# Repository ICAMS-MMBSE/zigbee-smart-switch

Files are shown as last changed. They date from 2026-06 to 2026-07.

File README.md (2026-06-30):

# zigbee-smart-switch

A Zigbee-based smart switch system for remote dehumidifier control, built for Industry 4.0 reliability, connectivity, and remote management.

## Purpose
- Build a smart switch to control a system of dehumidifiers remotely
- Integrate IoT connection through Mosquitto

### High-Level System Diagram

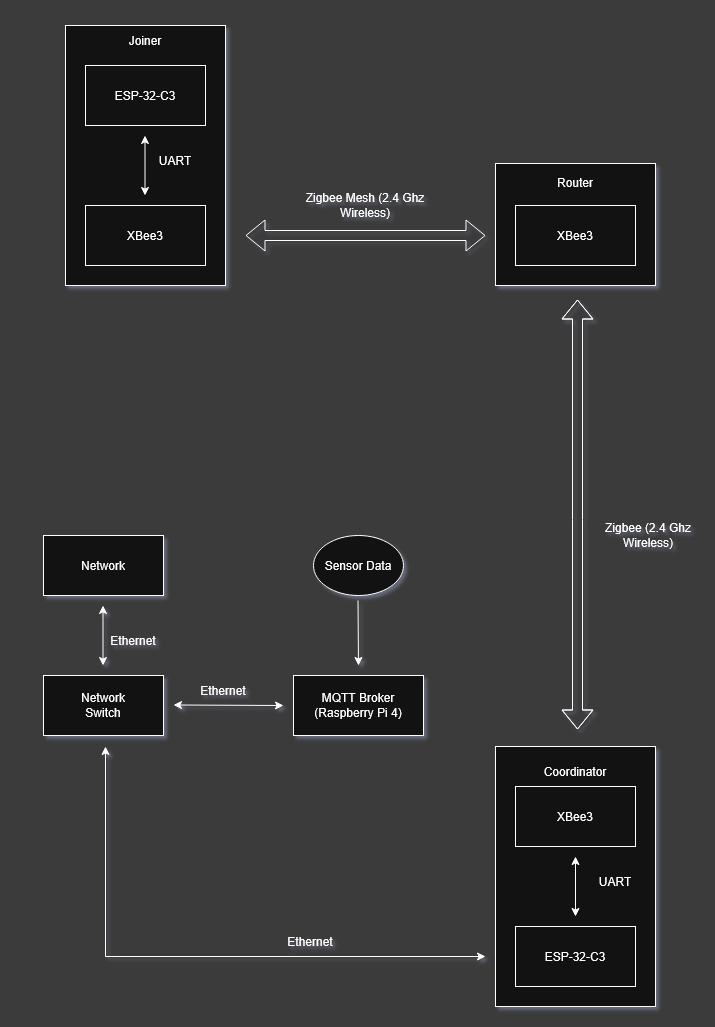
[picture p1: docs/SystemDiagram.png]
System Diagram


## Frameworks & Software

| Tool | Purpose |
|---|---|
| [Digi XCTU](https://www.digi.com/products/embedded-systems/digi-xbee/digi-xbee-tools/xctu) | Programs XBee modules |
| [PlatformIO](https://platformio.org/) | Build system and library manager for all firmware |
| [Mosquitto](https://github.com/eclipse-mosquitto/mosquitto) | MQTT broker |

## Firmware

Firmware is written in C using the ESP-IDF framework with FreeRTOS, built and flashed via VS Code with the PlatformIO extension.

### Setup

1. Install [VS Code](https://code.visualstudio.com/) and the [PlatformIO extension](https://platformio.org/install/ide?install=vscode)
2. Open `coord_esp32-c3/` or `join_esp32-c3/` as the workspace root in VS Code
3. PlatformIO will auto-detect the target from `platformio.ini`
4. Build and flash via the PlatformIO toolbar, or `pio run -t upload`

### Programming the XBee Modules

> **Note:** You **must** use the XBee Grove Development Board and XCTU to program the XBee modules. Plug in with USB micro-B and add device to XCTU.

| | Coordinator | Joiner | Router |
| --- | --- | --- | --- |
| **CE** Device Role | Form Network [1] | Join Network [0] | Join Network [0] |
| **ID** Extended PAN ID | 1234 | 1234 | 1234 |
| **JV** Coordinator Verification | Enabled [1] | Disabled [0] | Disabled [0] |
| **JN** Join Notification | Disabled [0] | Enabled [1] | Enabled [1] |
| **NI** Node Identifier | SS_Comm | SS_x (0...) | RT_x (0...) |
| **BD** UART Baud Rate | 115200 | 115200 | 115200 |
| **AP** API Enable | API Mode Without Escapes [1] | API Mode Without Escapes [1] | API Mode Without Escapes [1] |
| **SM** Sleep Mode | No Sleep [0] | No Sleep [0] | No Sleep [0] |
| **EE** Encryption Enable | Disabled [0] | Disabled [0] | Disabled [0] |

### Firmware Structure

#### Coordinator (`firmware/coord_esp32-c3/`)
```
config.h
xbee.h/.c       — raw API frame TX/RX, AT commands, ping, RX task
discovery.h/.c  — ND-based dynamic node table
relay.h/.c      — command routing
button.h/.c     — physical button, triggers toggle to all nodes
ethernet.h/.c   — W5500 SPI ethernet, DHCP
mqtt.h/.c       — MQTT client, command handler (switch/+/cmd), state publisher
main.c
```

#### Joiner (`firmware/joiner_esp32-c3/`)
```
config.h
xbee.h/.c       — raw API frame TX/RX, state reporting
relay.h/.c      — relay GPIO control
button.h/.c     — manual override, reports state to coordinator
main.c
```

### Key Technical Notes

- All XBee communication uses manually constructed raw API frames
- Frame types used: `0x10` ZBTxRequest, `0x08` AT command, `0x88` AT response, `0x90` ZB RX, `0x8B` TX status

## Hardware

### Coordinator
- ESP32-C3 Super Mini + XBee3 Zigbee 3.0 TH + W5500 Ethernet

### Joiner
- ESP32-C3 Super Mini + XBee3 Zigbee 3.0 TH

## Raspberry Pi Broker Setup

The Pi runs a Mosquitto MQTT broker and connects directly to the coordinator via ethernet.

### Mosquitto
```bash
sudo apt update && sudo apt install -y mosquitto mosquitto-clients
sudo systemctl enable mosquitto
printf 'listener 1883\nallow_anonymous true\n' | sudo tee /etc/mosquitto/conf.d/local.conf
sudo systemctl restart mosquitto
```

### Broker Connection

The coordinator connects to the broker at a hardcoded hostname in `mqtt.c`:

```c
.broker.address.uri = "mqtt://rpi3.local:1883"
```

> **Production note:** This hostname is compiled into the firmware. If the broker host changes (different Pi, renamed host, or production deployment), update the URI in `mqtt.c` and reflash the coordinator. A `.local` hostname requires mDNS resolution to be enabled in the firmware (`CONFIG_LWIP_DNS_SUPPORT_MDNS_QUERIES=y`); if mDNS resolution is unreliable on the network, substitute the broker's IP address directly. A future revision could replace this with mDNS service discovery (`_mqtt._tcp`) to remove the hardcoded dependency entirely.

### MQTT Topics
| Topic | Direction | Description |
|---|---|---|
| `switch/all/cmd` | Pi → Coordinator | Command all nodes |
| `switch/SS_<n>/cmd` | Pi → Coordinator | Command individual node |
| `switch/SS_<n>/state` | Coordinator → Pi | Per-node joiner state report |

Supported commands: `ON`, `OFF`, `TOGGLE`, `POLL`

### Examples
```bash
# All nodes on / off
mosquitto_pub -h localhost -t "switch/all/cmd" -m "ON"
mosquitto_pub -h localhost -t "switch/all/cmd" -m "OFF"

# Individual node
mosquitto_pub -h localhost -t "switch/SS_0/cmd" -m "ON"
mosquitto_pub -h localhost -t "switch/SS_1/cmd" -m "TOGGLE"

# Poll without changing state
mosquitto_pub -h localhost -t "switch/SS_1/cmd" -m "POLL"
mosquitto_pub -h localhost -t "switch/SS_0/cmd" -m "POLL"

# Subscribe to all state updates
mosquitto_sub -h localhost -t "switch/+/state" -v
```

## References
- [Digi XBee 3](https://hub.digi.com/support/products/digi-xbee/digi-xbee3/)
- [Digi XBee API Frame Reference](https://docs.digi.com/resources/documentation/digidocs/rf-docs/blu/blu-api-frames_c.html)
- [XBee Grove Development Board User Guide](https://docs.digi.com/resources/documentation/digidocs/pdfs/90001457-13.pdf)
- [ESP-IDF Programming Guide](https://docs.espressif.com/projects/esp-idf/en/latest/)
- [Digi XBee Python Library (not used, but helpful)](https://xbplib.readthedocs.io/en/latest/index.html)

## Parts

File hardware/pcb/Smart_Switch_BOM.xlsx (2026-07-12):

Coordinator & Joiner BOM: | Note: | This list includes parts for 1 Coordinator, 3 Joiners, and 3 Routers (initial demo order) |  |  |  | PCB Manufacturers: | Note: The minimum number of boards is 5
Part | Qty. | Price | Purpose | Board | Already Have? |  | PCB Way | JLPCB
ESP32-C3 Super Mini (10 PCS) (https://www.amazon.com/ESP32-C3-Development-Bluetooth-Running-Frequency/dp/B0DFWG87JS) | 10 | $29.69 | Logic MCU | Coordinator & Joiner | X | Coordinator Boards x5 | $5.00 | $4.00
XB3-24Z8UT-J (https://www.digikey.com/en/products/detail/digi/XB3-24Z8UT-J/8130933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) | 7 | $23.52 (each) | Radio Module | All | 5 | Joiner Boards x5 | $27.00 | $8.70
WIZ850IO (https://www.digikey.com/en/products/detail/wiznet/WIZ850IO/8789619) | 1 | $20.36 | Coord. Ethernet | Coordinator | X | Router Boards x5 | $5.00 | $4.00
Adafruit USB-C breakout 4090 (https://www.digikey.com/en/products/detail/adafruit-industries-llc/4090/9951930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) | 4 | $2.95 | Coord. & Routers USB-C Power | Coordinator & Router | X | Build Time | 3-4 days | 3 days
10kΩ resistor | 7 | X | Xbee RST pull-up | All | ✓ | Offers / Coupons | $5.00 off | $15.00 off
5.1kΩ resistor | 4 | X | USB-C CC | Coordinator & Router | ✓ | Shipping (all ordered together) | $30.30 | $28.12
330Ω resistor | 3 | X | Relay Transistor Base connection | Joiner | ✓ | Total cost (all ordered together, with coupon) | $84.42 | $27.82
5mm LED | 3 | X | Joiner Debug LED | Joiner | ✓
Push Button (https://www.digikey.com/en/products/detail/e-switch/RP3502ARED/280448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) | 3 | $2.32 (each) | Manual switch | Joiner | X
2N3904 NPN transistor | 3 | X | Relay switching logic | Joiner | ✓
1x08 Female 2.54mm Header | 12 | X | ESP-32 and USB-C Headers | All | ✓
1x10 Female 2.00mm Header (https://www.digikey.com/en/products/detail/sullins-connector-solutions/NPPN101BFCN-RC/804812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) | 14 | $0.72 (each) | XBee3 Headers | All | X
1x06 Female 2.54mm Header | 2 | X | Ethernet Module Headers | Coordinator | ✓
HLK-PM12 (3 PCS) (https://www.amazon.com/dp/B0B63WP3LF?lv=shuf&channelId=500&plpRedirect=mhFallback&th=1) | 3 | $13.99 | 120V to 12V converter | Joiner | X
HLK-PM01 (5 PCS) (https://www.amazon.com/dp/B01B7G6LYE?lv=shuf&channelId=500&plpRedirect=mhFallback&th=1) | 5 | $18.51 | 120V to 5V converter | Joiner | X
30A Relay (https://www.digikey.com/en/products/detail/te-connectivity-potter-brumfield-relays/T9AS1D12-12/254519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) | 3 | $6.35 (each) | 30A Relay Switching Mains In | Joiner | X
1N4007 Diode | 3 | X | Flyback Diode | Joiner | ✓
100Ω 1W resistor (https://www.digikey.com/en/products/detail/yageo/MFR100FTF52-100R/9131275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) | 3 | $0.21 (each) | Snubber | Joiner | X
0.1µF X2 275VAC cap (https://www.digikey.com/en/products/detail/tdk/B32922C3104K026/21191938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) | 3 | $0.54 (each) | Snubber | Joiner | X
Fuse Holder, 6.3 x 32mm, 300V, 15A (https://www.digikey.com/en/products/detail/eaton-electronics-division/BK-S-8002-1X-R/1877082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) | 3 | $1.12 (each) | Fuse holder | Joiner | X
Fuse, 6.3 x 32mm, Glass, Slow-Blow, 250V, 15A (https://www.digikey.com/en/products/detail/eaton-electronics-division/BK-MDL-15-R/954320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) | 3 | $1.95 (each) | Fuse to protect line in | Joiner | X
Screw Terminals (https://www.digikey.com/en/products/detail/phoenix-contact/1729131/260616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) | 6 | $1.44 (each) | Connects mains in and mains out | Joiner | X
Male IEC Connector (https://www.digikey.com/en/products/detail/adam-tech/IEC-A-2/9832396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) | 3 | $1.45 (each) | Mains in connection | Joiner | X
Female NEMA Connector (https://www.digikey.com/en/products/detail/qualtek/739W-X2-03/245569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) | 3 | $1.47 (each) | Mains out (dehumid) connection | Joiner | X
12 AWG Wire 10' (https://www.digikey.com/en/products/detail/remington-industries/SJOOW1203-10/14318220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) | 2 | $58.95 | Mains connections | Joiner | X
U.FL to RP-SMA (https://www.digikey.com/en/products/detail/sparkfun-electronics/18569/15652895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) | 7 | $2.94 (each) | Connects antenna to XBee3 | All | X
2.4GHZ DIPOLE ANTENNA RP-SMA (https://www.digikey.com/en/products/detail/te-connectivity-linx/ANT-2.4-LCW-RPS/9607800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) | 7 | $3.76 (each) | Antenna for range | All | X
LDO (https://www.digikey.com/en/products/detail/texas-instruments/TLV75733PDBVR/9343364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) | 3 | $0.34 (each) | Convert 5V USB to 3.3V | Router | X

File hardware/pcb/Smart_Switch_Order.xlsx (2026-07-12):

Smart Switch Components & PCBs:
Part | Qty. | Price
ESP32-C3 Super Mini (10 PCS) (https://www.amazon.com/ESP32-C3-Development-Bluetooth-Running-Frequency/dp/B0DFWG87JS) | 10 | $29.69
WIZ850IO (https://www.digikey.com/en/products/detail/wiznet/WIZ850IO/8789619) | 1 | $20.36
Adafruit USB-C breakout 4090 (https://www.digikey.com/en/products/detail/adafruit-industries-llc/4090/9951930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) | 4 | 2.95 (each)
Push Button (https://www.digikey.com/en/products/detail/e-switch/RP3502ARED/280448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) | 3 | $2.32 (each)
1x10 Female 2.00mm Header (https://www.digikey.com/en/products/detail/sullins-connector-solutions/NPPN101BFCN-RC/804812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) | 14 | $0.72 (each)
HLK-PM12 (3 PCS) (https://www.amazon.com/dp/B0B63WP3LF?lv=shuf&channelId=500&plpRedirect=mhFallback&th=1) | 3 | $13.99
HLK-PM01 (5 PCS) (https://www.amazon.com/dp/B01B7G6LYE?lv=shuf&channelId=500&plpRedirect=mhFallback&th=1) | 5 | $18.51
30A Relay (https://www.digikey.com/en/products/detail/te-connectivity-potter-brumfield-relays/T9AS1D12-12/254519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) | 3 | $6.35 (each)
100Ω 1W resistor (https://www.digikey.com/en/products/detail/yageo/MFR100FTF52-100R/9131275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) | 3 | $0.21 (each)
0.1µF X2 275VAC cap (https://www.digikey.com/en/products/detail/tdk/B32922C3104K026/21191938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) | 3 | $0.54 (each)
Fuse Holder, 6.3 x 32mm, 300V, 15A (https://www.digikey.com/en/products/detail/eaton-electronics-division/BK-S-8002-1X-R/1877082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) | 3 | $1.12 (each)
Fuse, 6.3 x 32mm, Glass, Slow-Blow, 250V, 15A (https://www.digikey.com/en/products/detail/eaton-electronics-division/BK-MDL-15-R/954320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) | 3 | $1.95 (each)
Screw Terminals (https://www.digikey.com/en/products/detail/phoenix-contact/1729131/260616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) | 6 | $1.44 (each)
Male IEC Connector (https://www.digikey.com/en/products/detail/adam-tech/IEC-A-2/9832396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) | 3 | $1.45 (each)
Female NEMA Connector (https://www.digikey.com/en/products/detail/qualtek/739W-X2-03/245569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) | 3 | $1.47 (each)
12 AWG Wire 10' (https://www.digikey.com/en/products/detail/remington-industries/SJOOW1203-10/14318220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) | 1 | $58.95
U.FL to RP-SMA (https://www.digikey.com/en/products/detail/sparkfun-electronics/18569/15652895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) | 7 | $2.94 (each)
2.4GHZ DIPOLE ANTENNA RP-SMA (https://www.digikey.com/en/products/detail/te-connectivity-linx/ANT-2.4-LCW-RPS/9607800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) | 7 | $3.76 (each)
LDO (https://www.digikey.com/en/products/detail/texas-instruments/TLV75733PDBVR/9343364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) | 3 | $0.34 (each)
PCB Manufacturers: | Note: The minimum number of boards is 5
 | PCB Way | JLPCB
Coordinator Boards x5 | $5.00 | $4.00
Joiner Boards x5 | $27.00 | $8.70
Router Boards x5 | $5.00 | $4.00
Build Time | 3-4 days | 3 days
Offers / Coupons | $5.00 off | $15.00 off
Shipping (all ordered together) | $30.30 | $28.12
Total cost (all ordered together, with coupon) | $84.42 | $27.82
PCBWay (https://www.pcbway.com/?adwgc=666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)
JLCPCB (https://jlcpcb.com/?from=VGSU&gad_source=1&gad_campaignid=14179457750)

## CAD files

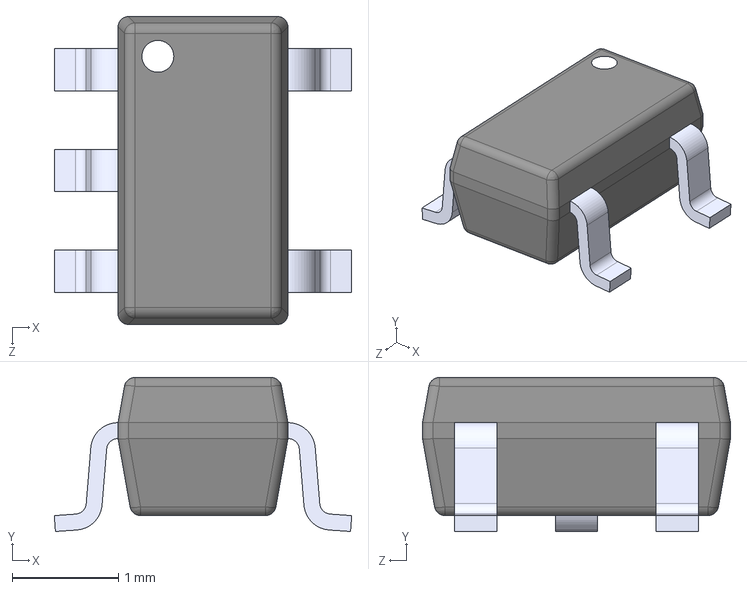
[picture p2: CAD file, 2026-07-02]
hardware/pcb/router/TLV75733PDBVR/TLV75733PDBVR.step
2.80 x 1.45 x 2.90 mm

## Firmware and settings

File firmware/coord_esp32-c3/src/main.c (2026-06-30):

#include "freertos/FreeRTOS.h"
#include "freertos/task.h"
#include "driver/uart.h"
#include "esp_log.h"
#include "ethernet.h"
#include "mqtt.h"
#include "xbee.h"
#include "discovery.h"
#include "relay.h"
#include "button.h"
#include "config.h"
#include <string.h>
#include <stdio.h>

static const char *TAG = "MAIN";

// Read newline-terminated commands from UART0 (USB serial) and dispatch them
static void console_task(void *arg)
{
    uart_config_t cfg = {
        .baud_rate  = 115200,
        .data_bits  = UART_DATA_8_BITS,
        .parity     = UART_PARITY_DISABLE,
        .stop_bits  = UART_STOP_BITS_1,
        .flow_ctrl  = UART_HW_FLOWCTRL_DISABLE,
    };
    uart_driver_install(UART_NUM_0, 256 * 2, 0, 0, NULL, 0);
    uart_param_config(UART_NUM_0, &cfg);

    uint8_t buf[128];
    uint8_t idx = 0;

    while (1) {
        uint8_t b;
        if (uart_read_bytes(UART_NUM_0, &b, 1, pdMS_TO_TICKS(10)) != 1) continue;

        if (b == '\n' || b == '\r') {
            if (idx == 0) continue;
            buf[idx] = '\0';
            char *cmd = (char *)buf;
            idx = 0;

            if (strcmp(cmd, "AT_PING") == 0) {
                xbee_ping();
            } else if (strcmp(cmd, "DISCOVER") == 0) {
                discover_nodes();
                print_node_table();
            } else if (strcmp(cmd, "NODES") == 0) {
                print_node_table();
            } else if (strncmp(cmd, "RELAY ", 6) == 0) {
                // Format: RELAY <nodeId> <0|1>
                char    node_id[16];
                uint8_t state;
                sscanf(cmd + 6, "%15s %hhu", node_id, &state);
                relay_cmd(node_id, state);
            } else if (strncmp(cmd, "TOGGLE ", 7) == 0) {
                relay_toggle(cmd + 7);
            } else if (strncmp(cmd, "POLL ", 5) == 0) {
                relay_poll(cmd + 5);
            } else {
                ESP_LOGW(TAG, "Unknown command: %s", cmd);
            }
        } else {
            if (idx < 127) buf[idx++] = b;
        }
    }
}

void app_main(void)
{
    ESP_LOGI(TAG, "Commissioner starting...");
    ethernet_init();
    button_init();
    xbee_init();
    vTaskDelay(pdMS_TO_TICKS(2000)); // let XBee3 boot
    discover_nodes();
    print_node_table();
    vTaskDelay(pdMS_TO_TICKS(3000)); // give joiners time to settle before polling
    relay_poll("ALL");
    xTaskCreate(xbee_task,    "xbee_task",    4096, NULL, 5, NULL);
    xTaskCreate(button_task,  "button_task",  2048, NULL, 5, NULL);
    xTaskCreate(console_task, "console_task", 4096, NULL, 4, NULL);
    mqtt_init();
    ESP_LOGI(TAG, "Commissioner ready");
}

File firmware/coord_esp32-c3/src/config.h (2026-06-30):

#pragma once
#include "driver/gpio.h"
#include "driver/uart.h"

// Pin definitions
#define BTN_PIN     GPIO_NUM_3
#define XBEE_RX     GPIO_NUM_1
#define XBEE_TX     GPIO_NUM_0
// UART
#define XBEE_UART       UART_NUM_1
#define XBEE_BAUD       115200
#define UART_BUF_SIZE   256
// XBee command bytes
#define CMD_OFF    0x00
#define CMD_ON     0x01
#define CMD_TOGGLE 0x02
#define CMD_POLL   0x03
// Node table
#define MAX_NODES 10
// W5500 SPI pins
#define W5500_SCLK  GPIO_NUM_5
#define W5500_MOSI  GPIO_NUM_7
#define W5500_MISO  GPIO_NUM_8
#define W5500_CS    GPIO_NUM_6
#define W5500_INT   GPIO_NUM_9
#define W5500_RST   GPIO_NUM_10

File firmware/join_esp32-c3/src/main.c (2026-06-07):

#include "freertos/FreeRTOS.h"
#include "freertos/task.h"
#include "esp_log.h"
#include "relay.h"
#include "button.h"
#include "xbee.h"

static const char *TAG = "MAIN";

void app_main(void)
{
    ESP_LOGI(TAG, "Joiner starting...");

    relay_init();
    button_init();
    xbee_init();

    xTaskCreate(xbee_task,   "xbee_task",   4096, NULL, 5, NULL);
    xTaskCreate(button_task, "button_task", 2048, NULL, 5, NULL);

    ESP_LOGI(TAG, "Joiner ready");
}

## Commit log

2026-05-17 Added joiner and commissioner communication sketches. Verified by onboard LED and pushbutton
2026-05-19 Wired FW to ZSS CLI swtich
2026-05-19 library import for kicad + readme update
    [XBee3_SMT.step, commissioner.kicad_pcb, commissioner.kicad_sch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]
2026-05-20 arduino outline addition
    [arduino_r4_outline.FCStd]
2026-05-21 arduino case, kicad basic setup
    [arduino_r4_case.FCStd, commissioner.kicad_sch, joiner.kicad_sch]
2026-05-25 Completed CommisionerV1 PCB design
    [XBee3_SMT.step, arduino_r4_case.FCStd, arduino_r4_outline.FCStd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]
2026-06-07 Migrate smart switch firmware from Arduino to ESP32 (S3/C3). Complete rewrite using ESP-IDF and FreeRTOS. Commissioner moves to ESP32-S3, joiner to ESP32-C3. Adds 2-way communication so the joiner re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
    [button.c, config.h, discovery.c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]
2026-06-07 W5500 ethernet and MQTT integration on commissioner
    - W5500 SPI ethernet via esp-eth-drivers component (SPI2, IO10-13)
    - Static IP 192.168.2.10 on commissioner, Pi broker at 192.168.2.1
    - esp-mqtt client subscribes to switch/all/cmd and switch/1/cmd
    - Publishes joiner state to switch/SS_1/state on change or poll
    - POLL command added to MQTT command handler
    - Joiner button press now reports state back to commissioner via XBee
    - Added W5500 pin definitions to config.h
    - Added Pi broker setup instructions to README
    [config.h, ethernet.c, main.c]
2026-06-16 Added eth, MQTT. Migrated coord from esp32-s3 to c3.
2026-06-22 Finished Coordinator PCB Design
    [ESP32-C3_SUPERMINI_TH.step, XBee3_SMT.step, commissioner_v1.kicad_pcb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]
2026-06-22 Joiner PCB began
    [Smart Switch BOM.xlsx, coordinator.kicad_pcb, coordinator.kicad_sch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]
2026-06-23 Made Joiner PCB Progress
    [ESP32-C3_SUPERMINI_TH.step, HLK-PM01.step, XBee3_SMT.step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]
2026-06-23 Began PCB BOM
    [Smart Switch BOM.xlsx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]
2026-06-23 Worked on PCB BOM
    [Smart Switch BOM.xlsx]
2026-06-23 Finished BOM. Updated README.
    [Smart Switch BOM.xlsx]
2026-06-30 Removed status LED from coord, allowed individual switching, replaced static IP with DHCP, proved router device (XBee3 module only), updated README
    [config.h, ethernet.c, main.c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]
2026-07-02 Modified BOM. Began Router PCB
    [TLV75733PDBVR.step, XBee3_SMT.step, arduino_r4_case.FCStd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]
2026-07-02 Modified BOM
    [Smart Switch BOM.xlsx]
2026-07-02 Stop tracking KiCad .history folders
2026-07-09 Designed router PCB
    [router.kicad_pcb, router.kicad_sch]
2026-07-10 Redesigned joiner
    [coordinator-B_Cu.gbr, coordinator-B_Mask.gbr, coordinator-B_Paste.gbr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]
2026-07-12 All PCBs finalized, ready to order
    [Smart Switch BOM.xlsx, Smart_Switch_BOM.xlsx, Smart_Switch_Order.xlsx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]
